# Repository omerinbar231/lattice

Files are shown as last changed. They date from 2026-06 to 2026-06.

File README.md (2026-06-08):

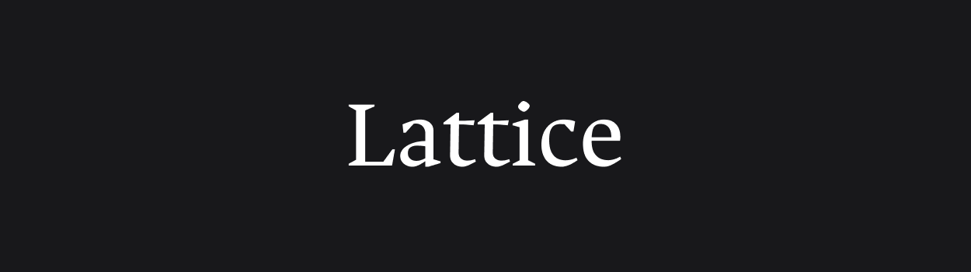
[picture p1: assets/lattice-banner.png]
Lattice


# Lattice Arm: Open Source Modular Detachable Low Cost Robotic Arm for Tool Use





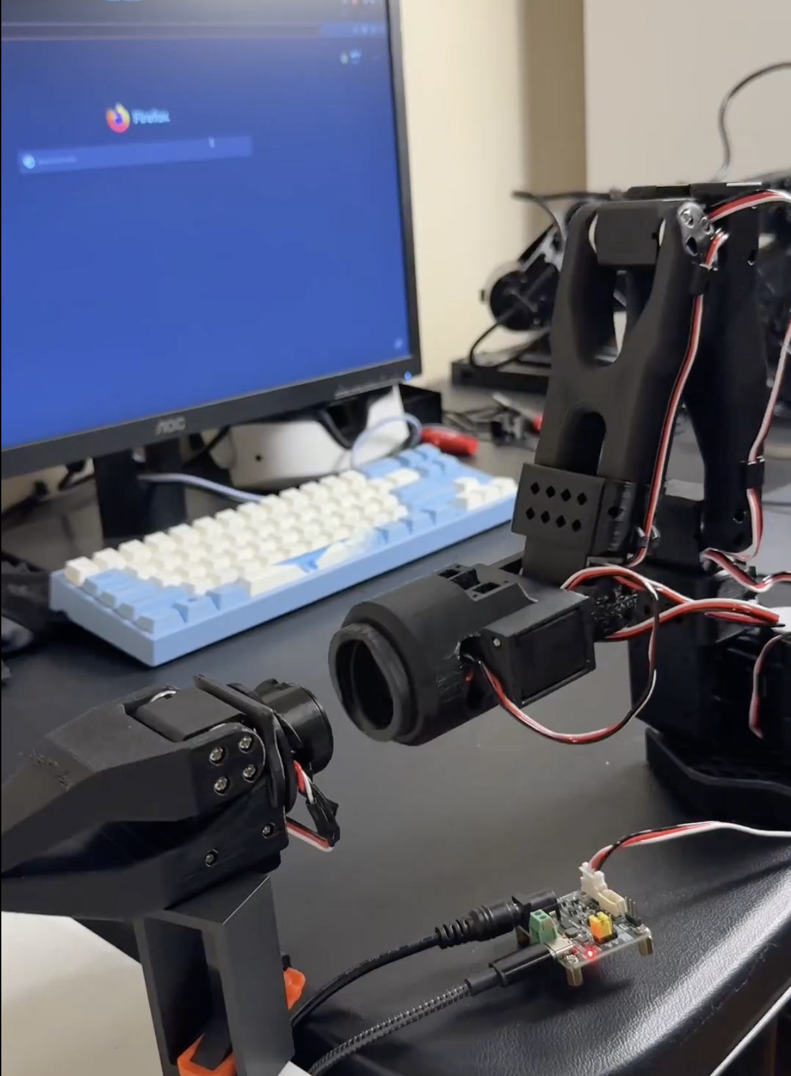
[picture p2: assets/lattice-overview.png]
Lattice overview


Lattice Arm is an open-source, low-cost robotic manipulator designed to be modular and detachable. This repo hosts the hardware design and build resources; pair it with [lerobot](https://github.com/ahadjawaid/lerobot/tree/lattice) on the `lattice` branch to teleoperate on the arm.

## News

- **2026-06-08** — Initial public release.

## BOM

The Lattice Arm reuses the SO-101 follower arm electronics and motors, so the bill of materials is split into the **Lattice** parts (unique to this repo) and the **SO-101 base arm** (the remaining standard parts). One full arm uses **6× Feetech STS 3215 servos** total — 2 in the Lattice upper section and 4 in the SO-101 base. Prices are in USD and referenced from the [SO-101 BOM](https://github.com/TheRobotStudio/SO-ARM100).

### Lattice

| Part | Qty | Unit Cost | Subtotal | Buy |
| --- | --- | --- | --- | --- |
| Feetech STS 3215 Servo 7.4V | 2 | $13.89 | $27.78 | [Seeed](https://www.seeedstudio.com/Feetech-ST-3215-C044-Heavy-Duty-Servo-7-4V-1-191-Gear-Reduction-p-6460.html) |
| 8 Pin Pogo Pin | 1 | $9.99 | $9.99 | [Amazon](https://www.amazon.com/dp/B0DT79W2VD) |
| PLA Filament — `lattice.3mf`, 189.11 g <sup>[1](#filament)</sup> | — | ~$20/kg | ~$3.78 | — |
| Jumper Wires M-M (optional) | 1 | ~$6.99 | — | [Amazon](https://www.amazon.com/dp/B07XJ97KD2) |
| **Total** | | | **~$41.55** | |

> [!NOTE]
> Screws for mounting the motors are included in the Feetech STS 3215 boxes. The optional jumper wires are excluded from the total.

### SO-101 Base Arm

| Part | Qty | Unit Cost | Subtotal | Buy |
| --- | --- | --- | --- | --- |
| Feetech STS 3215 Servo 7.4V | 4 | $13.89 | $55.56 | [Alibaba](https://www.alibaba.com/product-detail/Top-Seller-Low-Cost-Feetech-STS3215_1600999461525.html) |
| Motor Control Board | 1 | $10.60 | $10.60 | [Amazon](https://www.amazon.com/Waveshare-Integrates-Control-Circuit-Supports/dp/B0CTMM4LWK/) |
| USB-C Cable (2 pcs) | 1 | $7.00 | $7.00 | [Amazon](https://www.amazon.com/Charging-etguuds-Charger-Braided-Compatible/dp/B0B8NWLLW2/?th=1) |
| Power Supply | 1 | $10.00 | $10.00 | [Amazon](https://www.amazon.com/Facmogu-Switching-Transformer-Compatible-5-5x2-1mm/dp/B087LY41PV/) |
| Table Clamp (2 pcs) | 1 | $5.00 | $5.00 | [Amazon](https://www.amazon.com/Mr-Pen-Carpenter-Clamp-6inch/dp/B092L925J4/) |
| Screwdriver Set | 1 | $6.00 | $6.00 | [Amazon](https://www.amazon.com/Precision-Phillips-Screwdriver-Electronics-Computer/dp/B0DB227RTH) |
| PLA Filament — SO-101 base parts, 223.91 g <sup>[1](#filament)</sup> | — | ~$20/kg | ~$4.48 | — |
| **Total** | | | **~$98.64** | |

**Full arm total: ~$140.19** (Lattice ~$41.55 + SO-101 base ~$98.64), with **413.02 g** of filament.

<a name="filament">1</a>: Filament cost estimated at ~$20/kg PLA; adjust for your material and supplier.

## Instruction

See [`hardware/README.md`](hardware/README.md) for the print files, part list, and assembly.

## Contribution

Core contributors: **Ahad Jawaid** and **Juan Luna**.

Lattice is an active project and we welcome help. See [CONTRIBUTING.md](CONTRIBUTING.md) for the current roadmap and how to get involved.

## Citation

```bibtex
@misc{jawaid2026lattice,
    author = {Jawaid, Ahad and Luna, Juan},
    title = {Lattice Arm: Open Source Modular Detachable Low Cost Robotic Arm},
    howpublished = "\url{https://github.com/ahadjawaid/lattice}",
    year = {2026}
}
```

## Acknowledgement

Built on top of [SO-ARM100](https://github.com/TheRobotStudio/SO-ARM100) and [LeRobot](https://github.com/huggingface/lerobot). And repo inspired by [XLeRobot](https://github.com/Vector-Wangel/XLeRobot).

## Disclaimer

> [!NOTE]
> If you build, buy, or develop a Lattice Arm based on this repo, you will be fully responsible for all the physical and mental damages it does to you or others. No warranties or guarantees are made regarding safety, performance, or fitness for any particular use.

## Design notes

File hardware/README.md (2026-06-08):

# Lattice Arm Hardware

The Lattice Arm is built on top of the [SO-101](https://github.com/TheRobotStudio/SO-ARM100) arm. This folder contains the 3D-printable parts, CAD source files, and assembly references for the Lattice-specific hardware — everything from the shoulder through the end effector and detachable connectors.

## 3MF Print Files

Two pre-arranged build plates are provided for Bambu Studio (or any slicer that supports `.3mf`).

### Lattice-only parts — `lattice.3mf`

Contains every part unique to the Lattice Arm: shoulder through end effector, including both detachable connectors. Use this if you already have SO-101 base-arm parts and only need to print the Lattice additions.

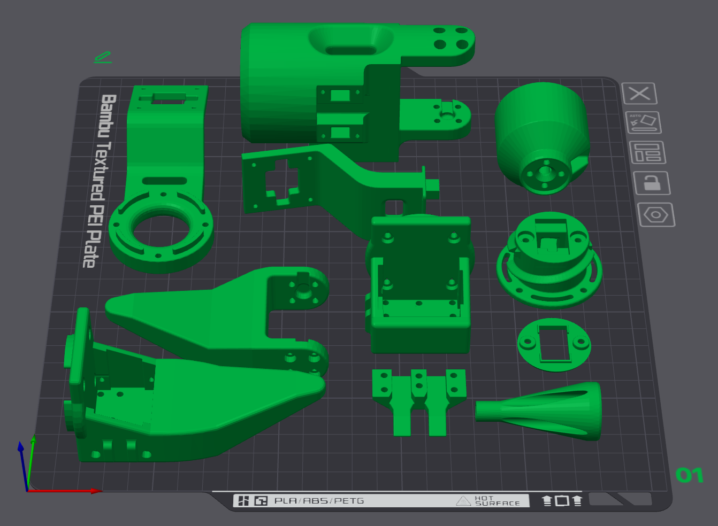
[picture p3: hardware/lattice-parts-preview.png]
Lattice-only print preview


### Full arm — `lattice-full-arm.3mf`

Contains the complete arm on two plates: SO-101 base-arm parts (plate 01) and all Lattice-specific parts (plate 02). Use this for a from-scratch full-arm print.

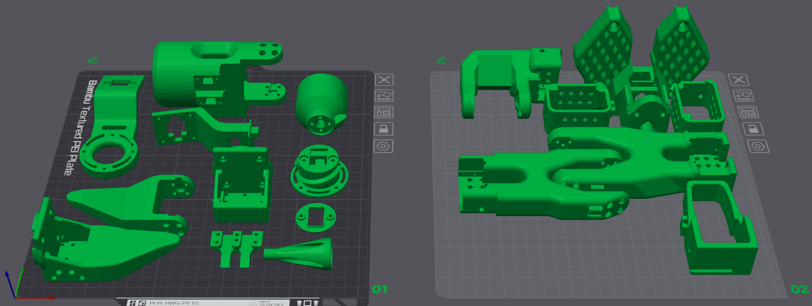
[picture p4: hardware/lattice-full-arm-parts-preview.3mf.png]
Full arm print preview


| File | What it includes |
|---|---|
| [`lattice.3mf`](lattice.3mf) | Lattice-only parts (shoulder → connectors → gripper) |
| [`lattice-full-arm.3mf`](lattice-full-arm.3mf) | SO-101 base parts + all Lattice parts |

## Part Files

Each part folder contains a preview image (`.png`), a mesh for printing (`.stl`), and a CAD source file (`.step`) where available.

| Folder | Parts | Role |
|---|---|---|
| [`Shoulder/`](Shoulder/) | `Shoulder` | Shoulder housing — mounts to the SO-101 base arm |
| [`Shoulder Connector/`](Shoulder%20Connector/) | `ConnectorPartA`, `ConnectorPartAcap` | Detachable shoulder connector |
| [`End Effector Connector/`](End%20Effector%20Connector/) | `ConnectorPartB`, `ConnectorPartBcap` | Detachable wrist / end-effector connector |
| [`End Effectors/Gripper/`](End%20Effectors/Gripper/) | `GripperPartA`, `GripperPartb` | Default parallel-jaw gripper |
| [`End Effectors/Screw Gripper/`](End%20Effectors/Screw%20Gripper/) | `ScrewComponent`, `GeneralMotorCasing` | Alternate screw-driven gripper |
| [`CasingHolder/`](CasingHolder/) | `CasingHolder` | Motor casing mount |
| [`Camera Accessories/`](Camera%20Accessories/) | `CameraAttachment`, `CameraAttachment2` | Optional egocentric camera mounts |

## Assembly

The Lattice upper arm attaches to the SO-101 base and is built in this order, base to tip:

```
SO-101 base arm  →  Shoulder  →  Shoulder Connector  →  End Effector Connector  →  Gripper
```

Each connector pair (`PartA` / `PartAcap`, `PartB` / `PartBcap`) forms a detachable joint so segments can be swapped without disassembling the full arm.

### 1. Shoulder

Mount the shoulder housing onto the SO-101 wrist/base-arm interface. The shoulder is the main structural block with side connector ports and a top cable-routing opening.

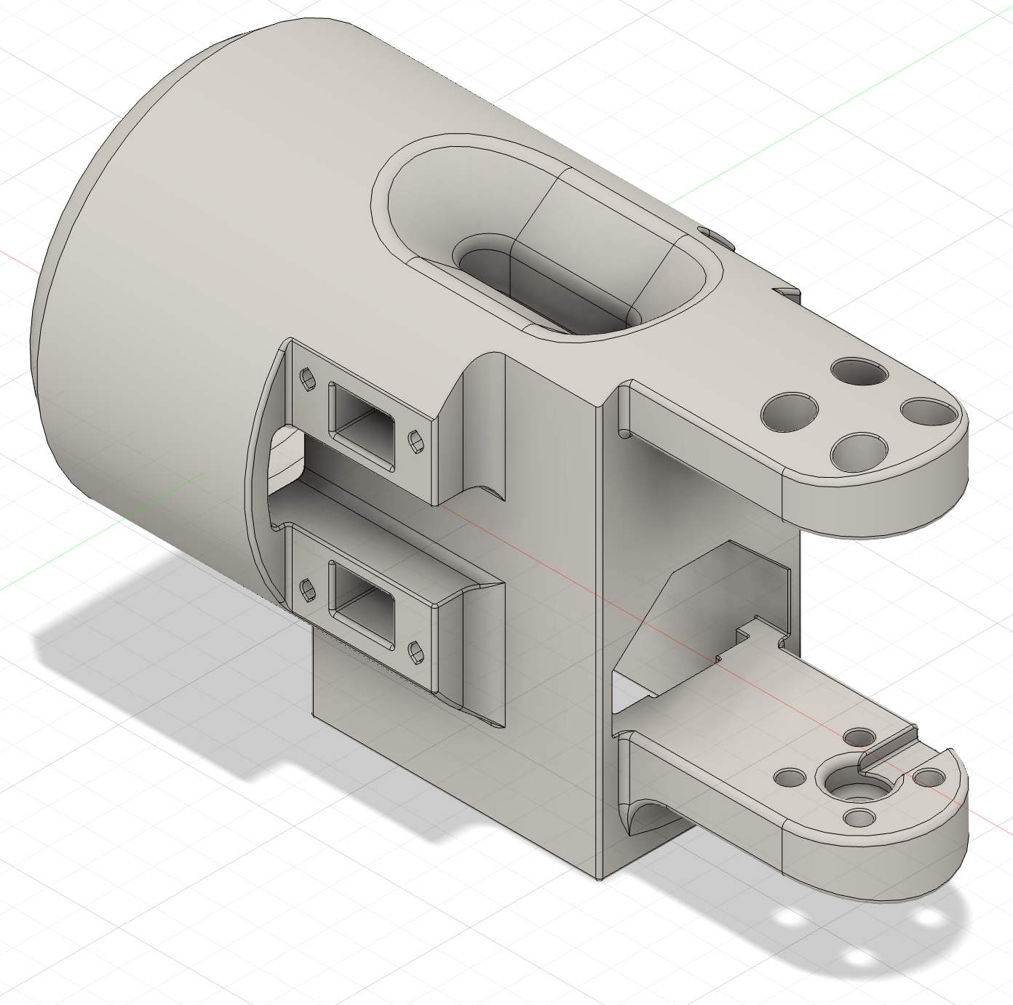
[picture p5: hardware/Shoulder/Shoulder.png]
Shoulder


### 2. Shoulder Connector

Attach `ConnectorPartA` to the shoulder. Seat `ConnectorPartAcap` to complete the detachable shoulder joint. This is the first modular break point — the arm above the shoulder can be removed here.

| Body | Cap |
|---|-----|
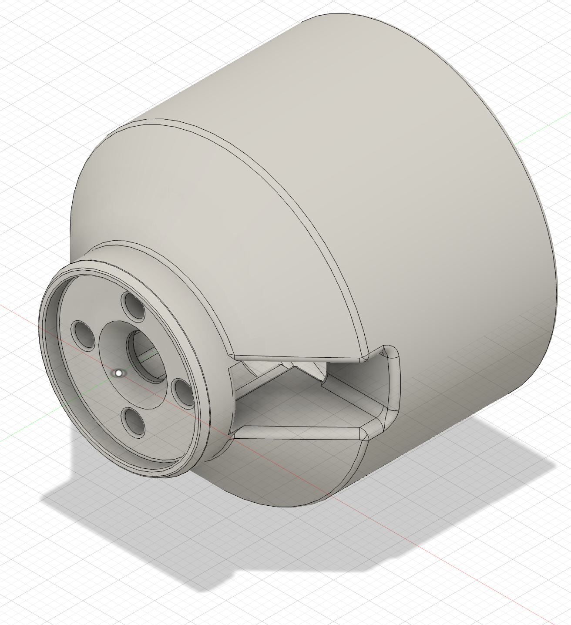
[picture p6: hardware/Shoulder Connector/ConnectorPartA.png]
ConnectorPartA
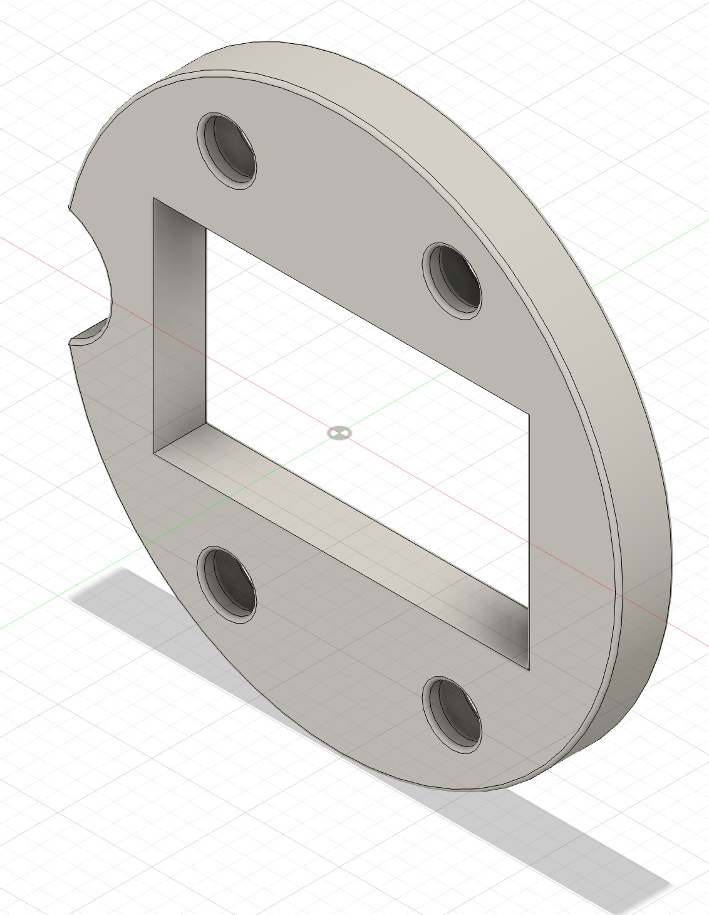
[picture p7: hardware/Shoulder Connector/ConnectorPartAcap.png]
ConnectorPartAcap
|  |  |

### 3. End Effector Connector

Bolt `ConnectorPartB` to the output of the shoulder connector. Attach `ConnectorPartBcap` to form the second detachable joint at the wrist.

| Body | Cap |
|---|-----|
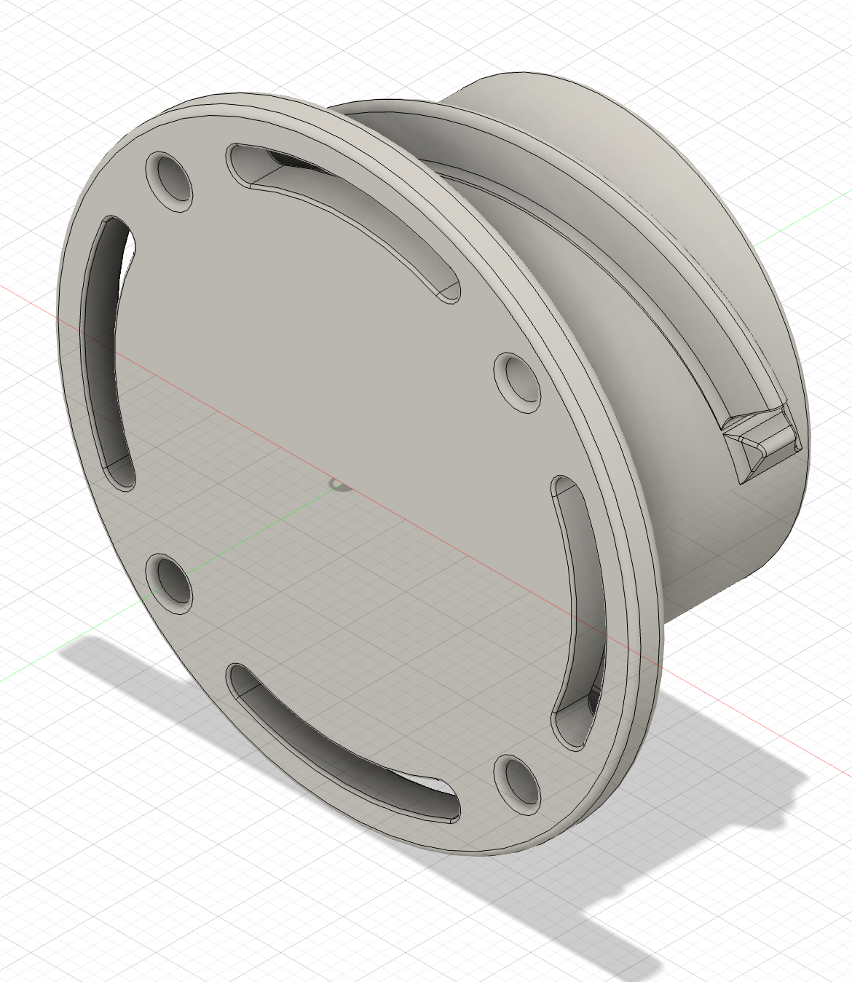
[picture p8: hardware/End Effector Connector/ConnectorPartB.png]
ConnectorPartB
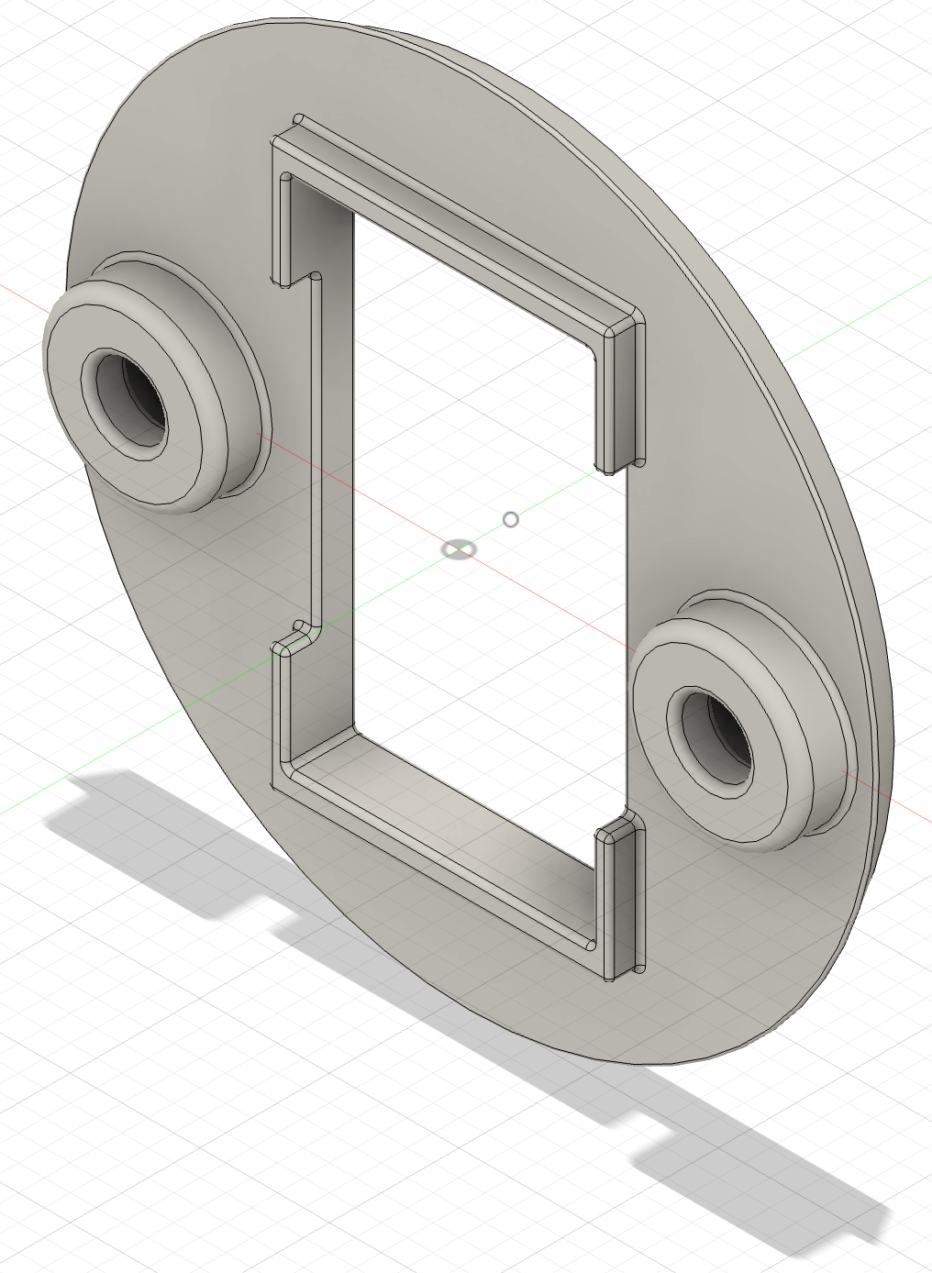
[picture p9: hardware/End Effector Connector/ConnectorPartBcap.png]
ConnectorPartBcap
|  |  |

### 4. Gripper

Mount the gripper onto the end effector connector.

| Finger A | Finger B |
|---|---|
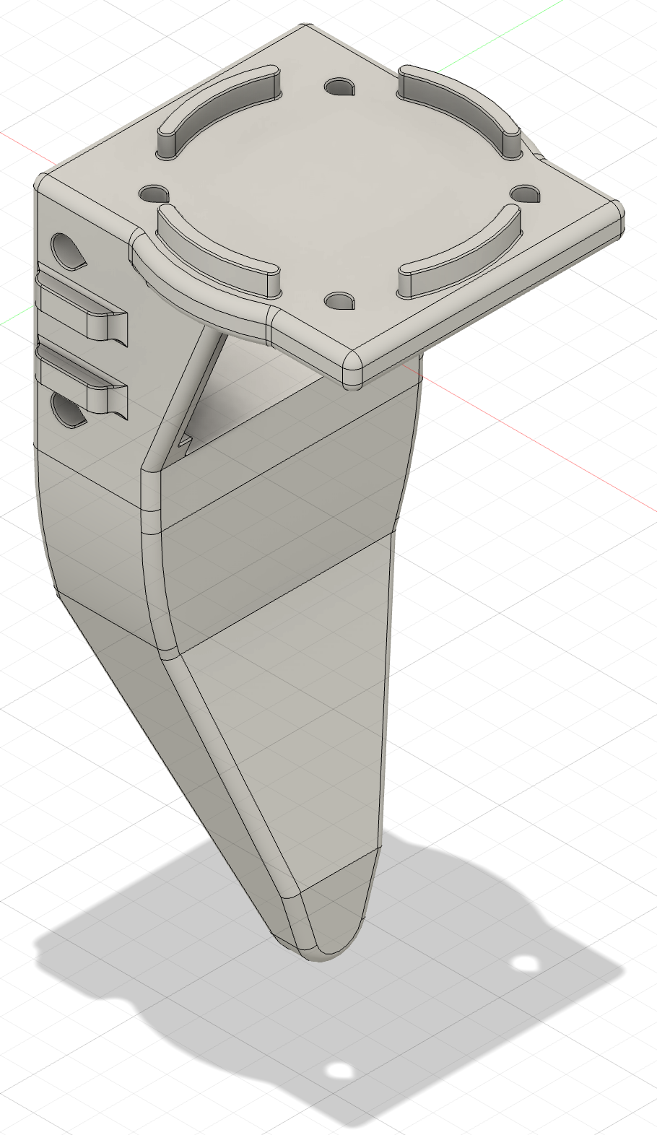
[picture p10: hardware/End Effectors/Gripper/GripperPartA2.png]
GripperPartA
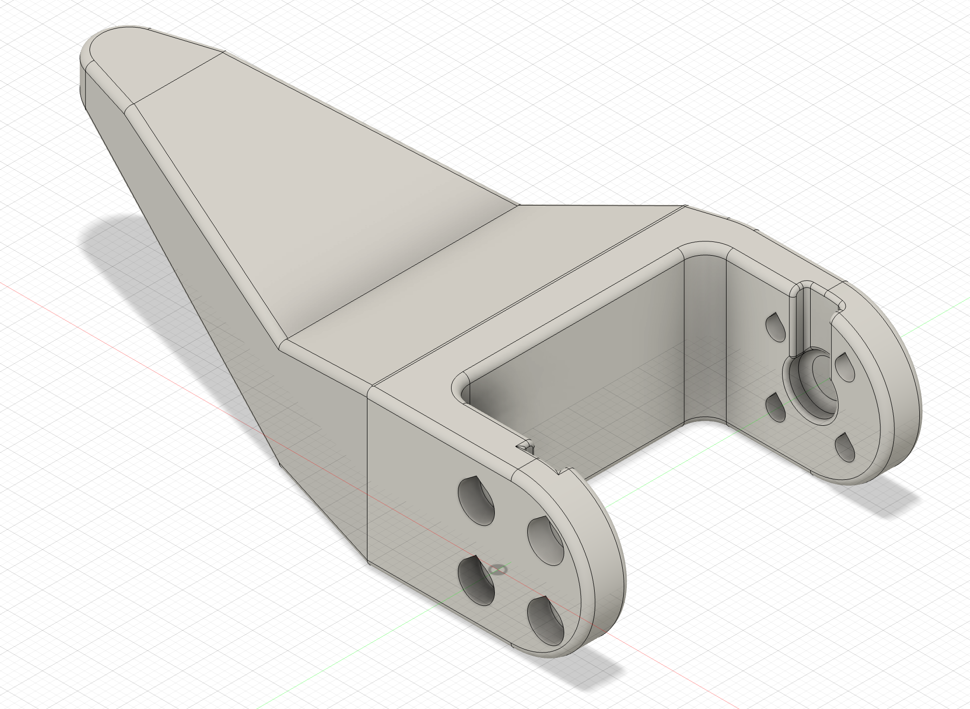
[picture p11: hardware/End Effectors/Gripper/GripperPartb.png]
GripperPartb
|  |  |

Install the gripper servo in [`CasingHolder/CasingHolder`](CasingHolder/CasingHolder.png) if using a dedicated motor housing.

## Optional Accessories

**Screw Gripper** — swap the default gripper for a lead-screw driven variant:

| Screw drive | Motor casing |
|---|---|
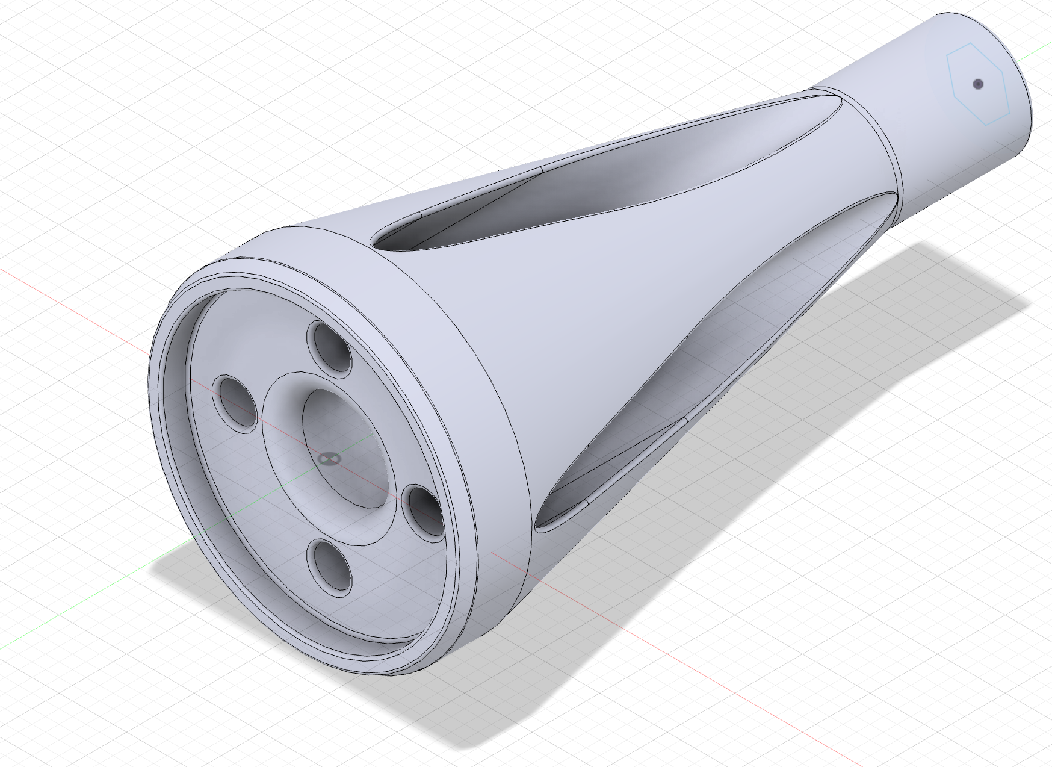
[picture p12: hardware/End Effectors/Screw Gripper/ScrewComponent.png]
ScrewComponent
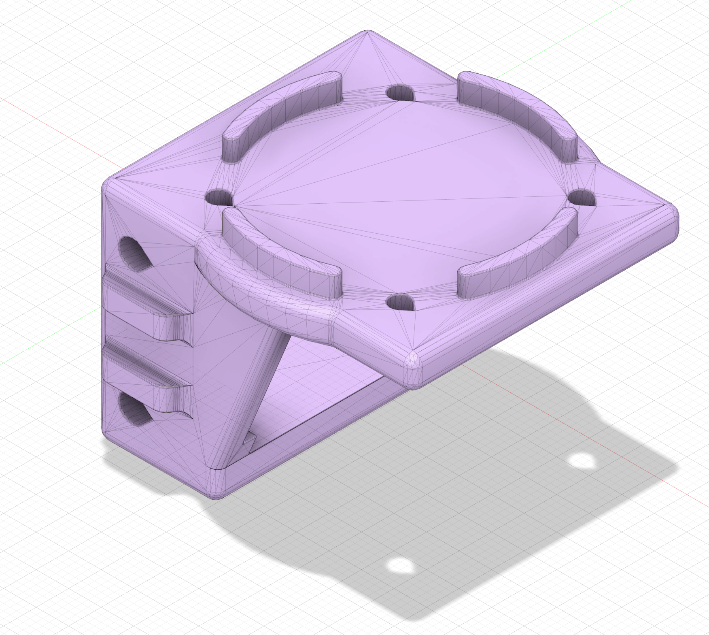
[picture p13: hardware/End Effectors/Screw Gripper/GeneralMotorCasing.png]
GeneralMotorCasing
|  |  |

**Camera mounts** — attach egocentric cameras to the arm:

| Mount A | Mount B |
|---|---|
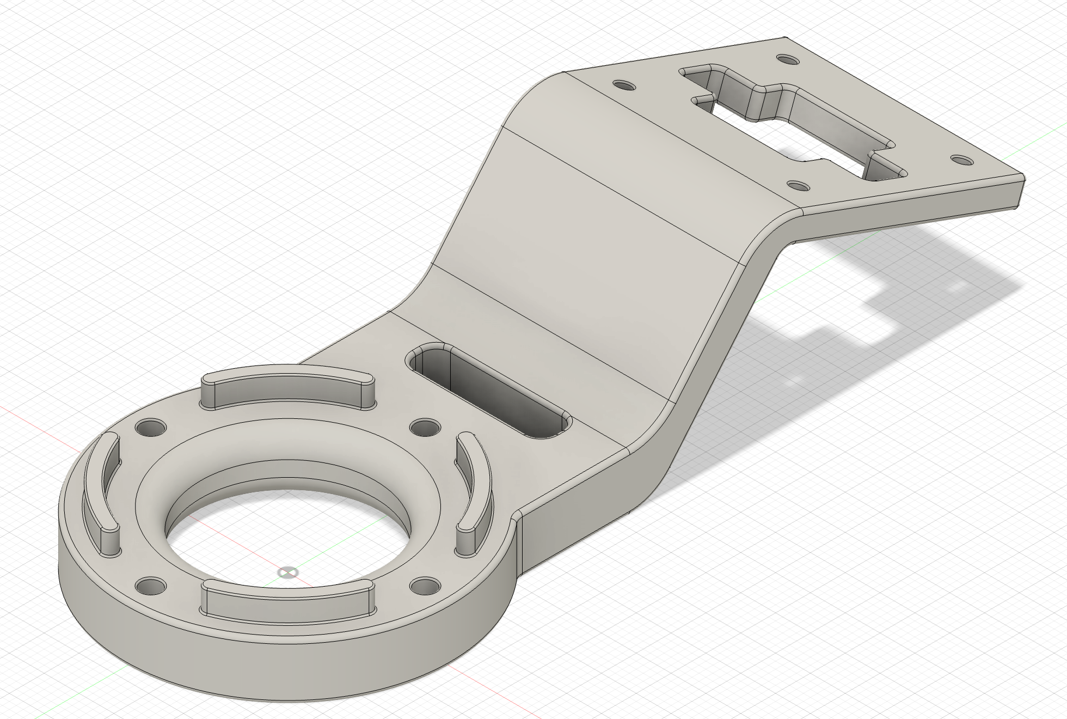
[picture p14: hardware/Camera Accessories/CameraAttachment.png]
CameraAttachment
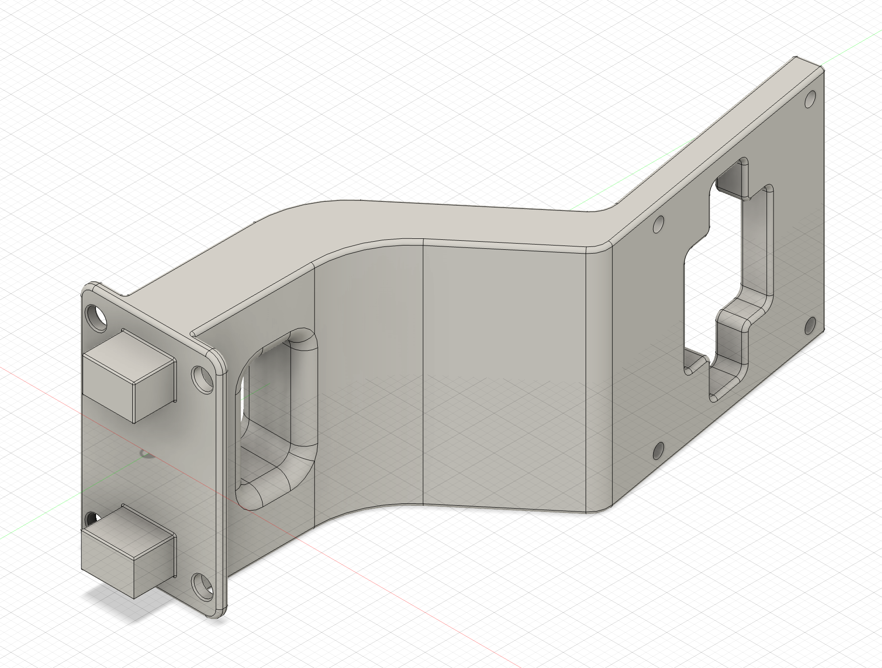
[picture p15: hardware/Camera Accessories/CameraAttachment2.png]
CameraAttachment2
|  |  |

## Software

To teleoperat, use the [lerobot `lattice` branch](https://github.com/ahadjawaid/lerobot/tree/lattice).

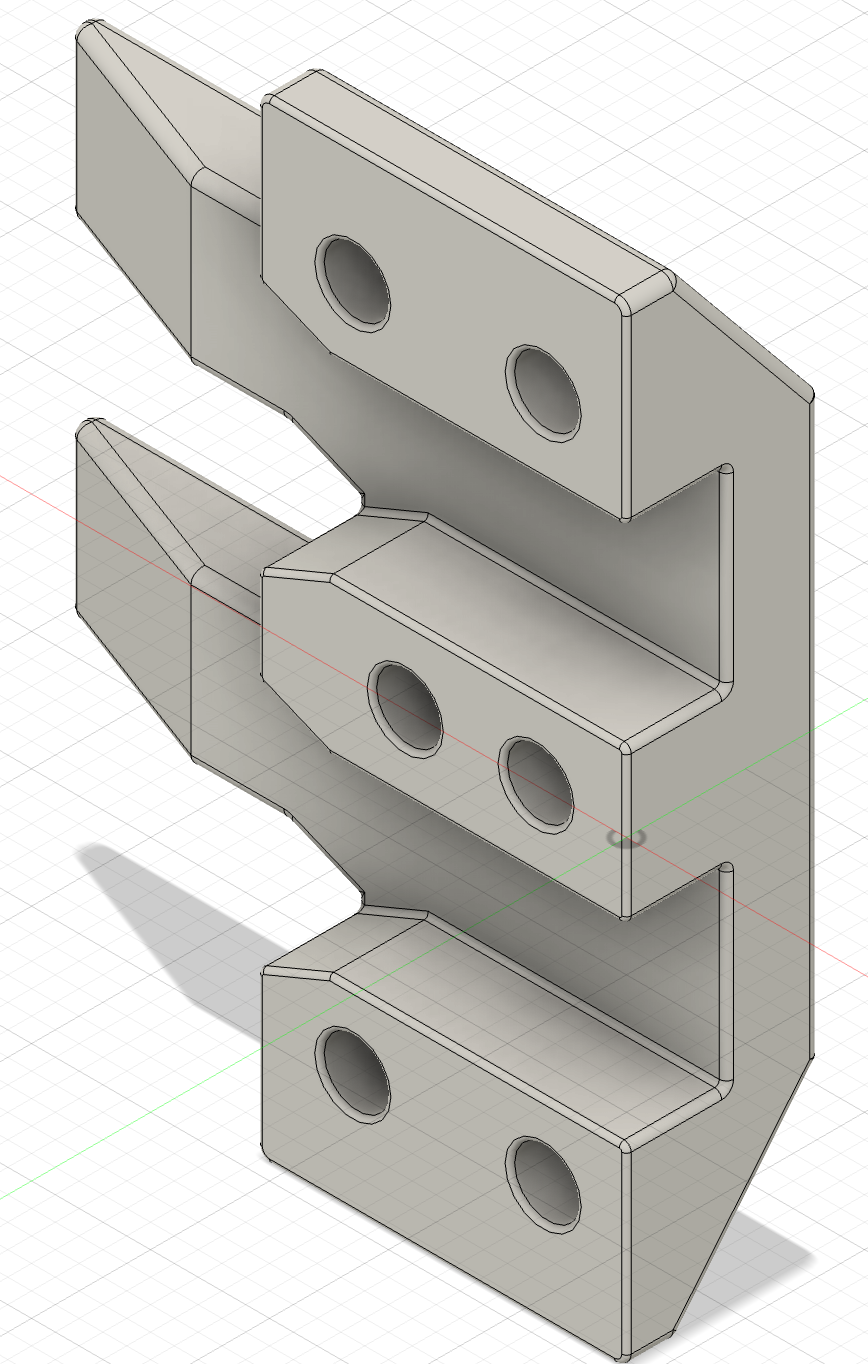
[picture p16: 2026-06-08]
hardware/CasingHolder/CasingHolder.png

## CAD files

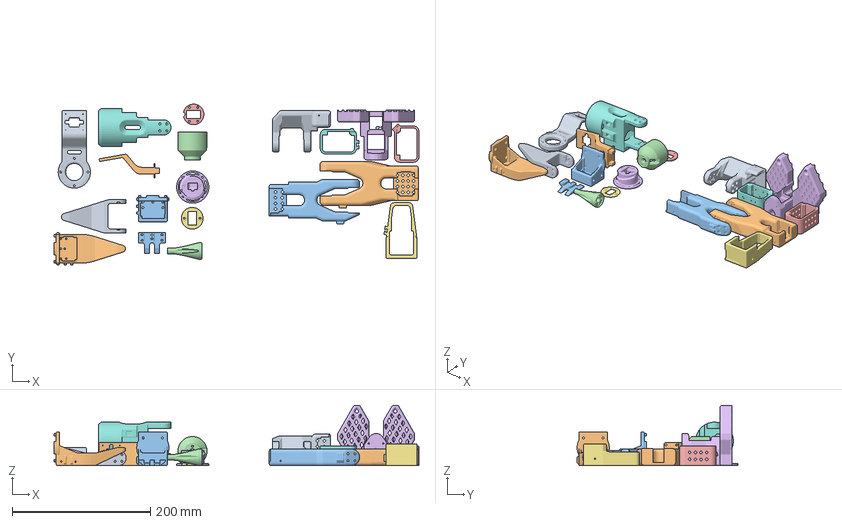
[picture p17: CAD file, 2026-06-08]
hardware/lattice-full-arm.3mf
527.2 x 232.3 x 87.0 mm
CameraAttachment.stl
CameraAttachment2.stl
CasingHolder.stl
ConnectorPartA.stl
ConnectorPartAcap.stl
ConnectorPartB.stl
ConnectorPartBcap.stl
HolderArmPart.stl
GripperPartb.stl
GripperPartA2.stl
GeneralMotorCasing.stl
ScrewComponent.stl
Ender_Follower_SO101.stl_1
Ender_Follower_SO101.stl_2
Ender_Follower_SO101.stl_3
Ender_Follower_SO101.stl_4
Ender_Follower_SO101.stl_5
Ender_Follower_SO101.stl_9
Ender_Follower_SO101.stl_10

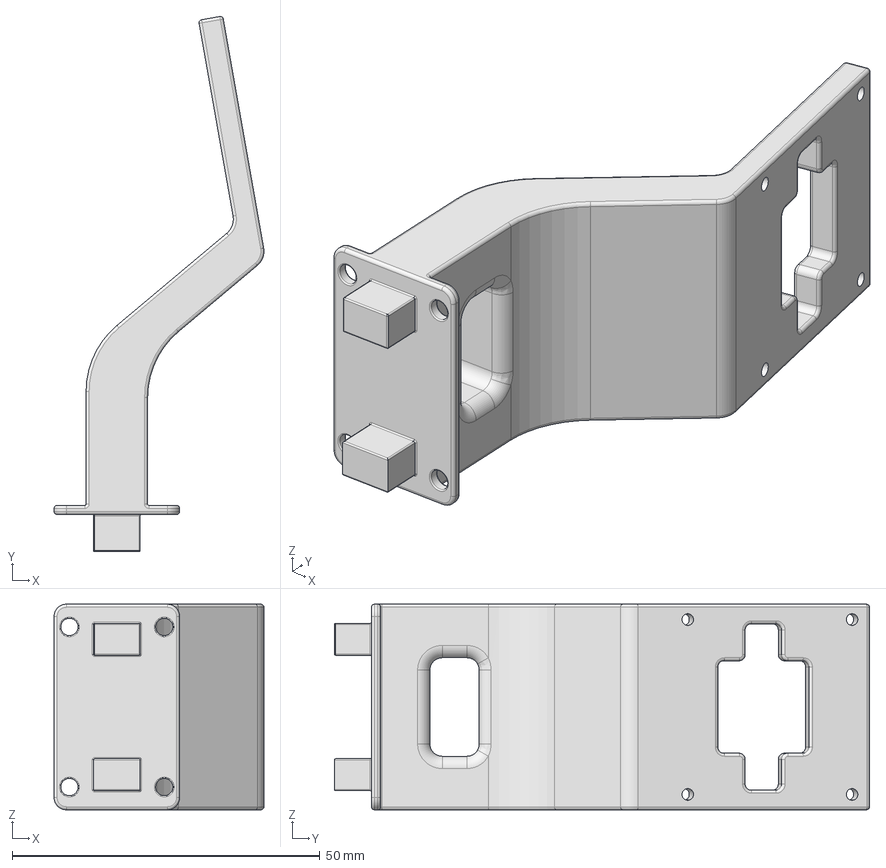
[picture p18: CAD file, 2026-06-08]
hardware/Camera Accessories/CameraAttachment2.step
34.1 x 86.9 x 33.4 mm

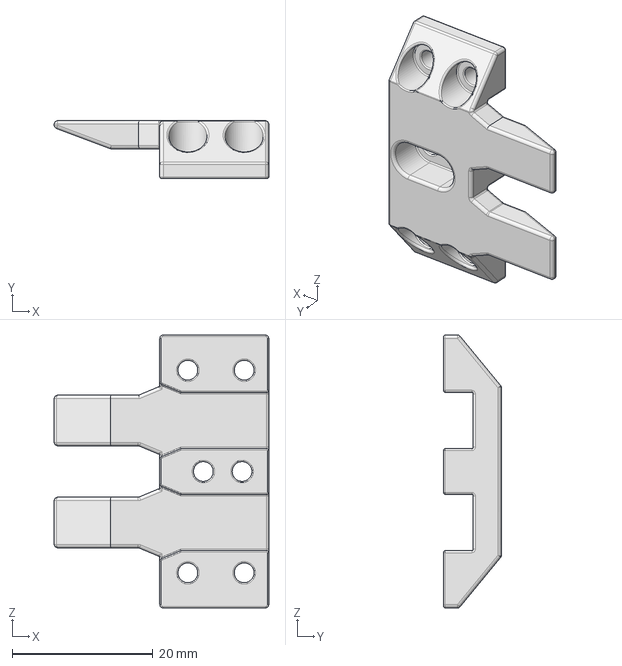
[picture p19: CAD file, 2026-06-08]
hardware/CasingHolder/CasingHolder.step
30.5 x 8.20 x 38.8 mm

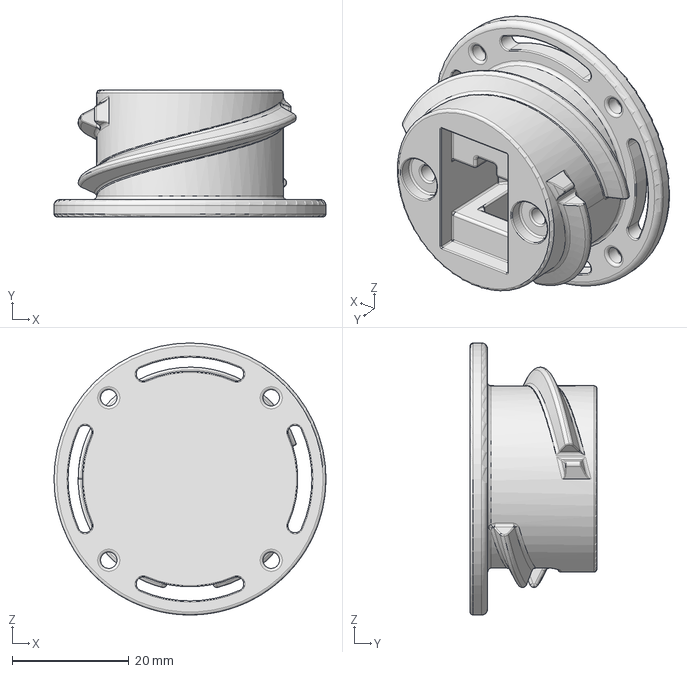
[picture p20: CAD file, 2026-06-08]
hardware/End Effector Connector/ConnectorPartB.step
46.6 x 21.8 x 46.6 mm

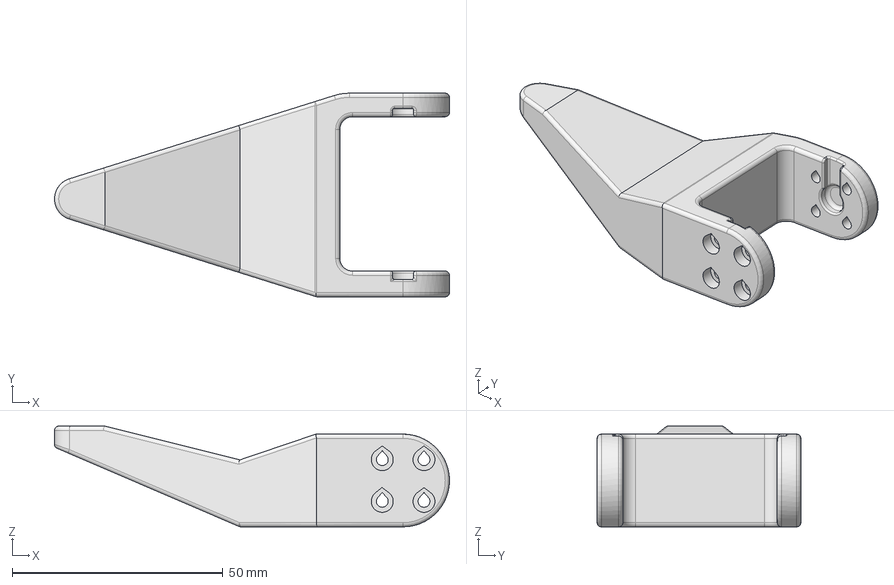
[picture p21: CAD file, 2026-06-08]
hardware/End Effectors/Gripper/GripperPartb.step
93.7 x 48.3 x 23.9 mm

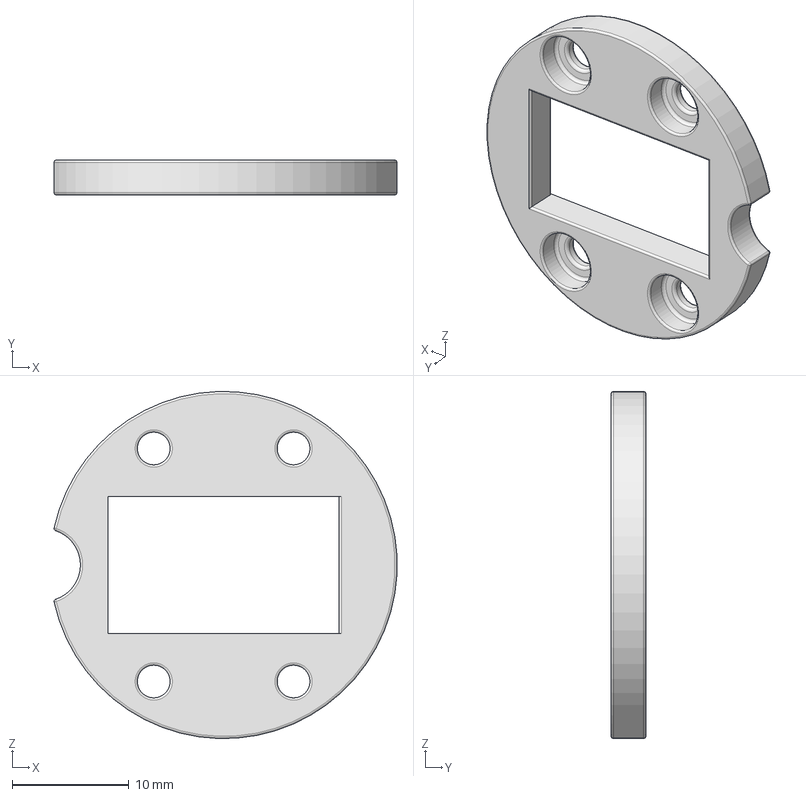
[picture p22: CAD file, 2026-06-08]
hardware/Shoulder Connector/ConnectorPartAcap.step
29.4 x 3.00 x 29.8 mm

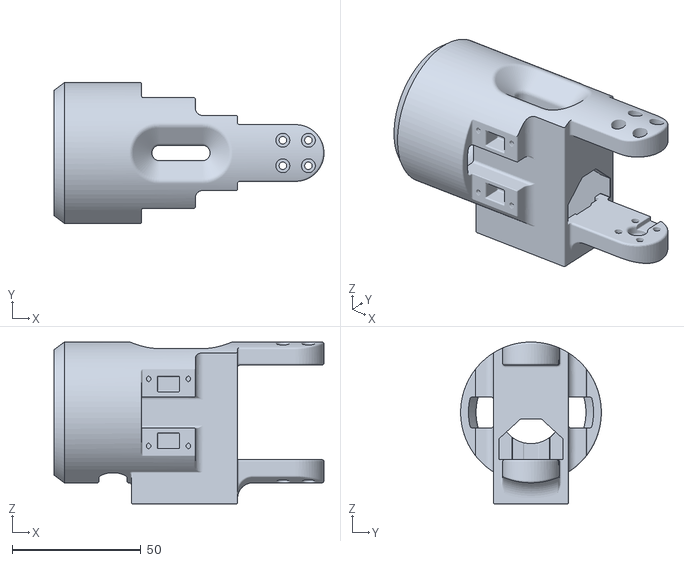
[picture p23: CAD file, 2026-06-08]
hardware/Shoulder/Shoulder.stl
104.7 x 54.6 x 62.8

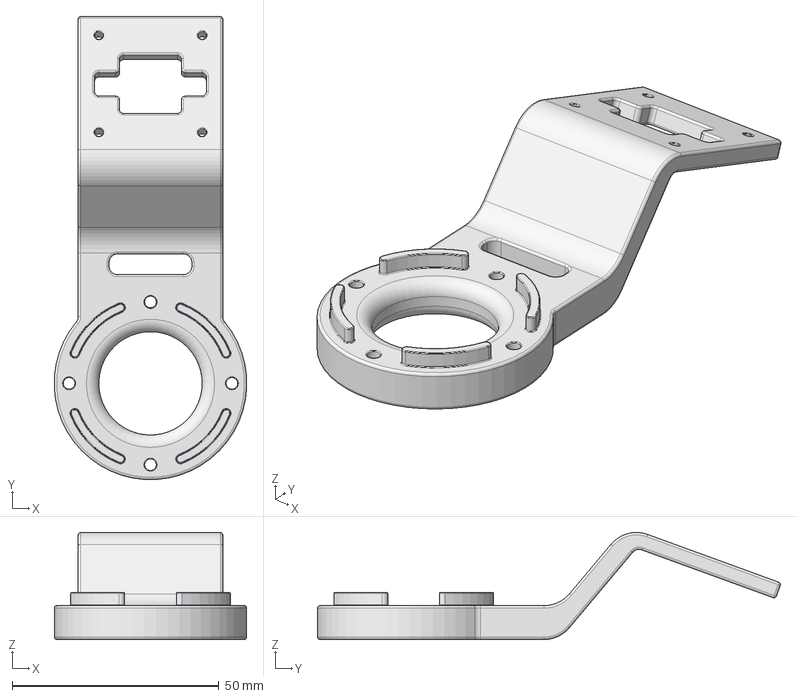
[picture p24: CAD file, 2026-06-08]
hardware/Camera Accessories/CameraAttachment.step
46.6 x 112.1 x 25.9 mm

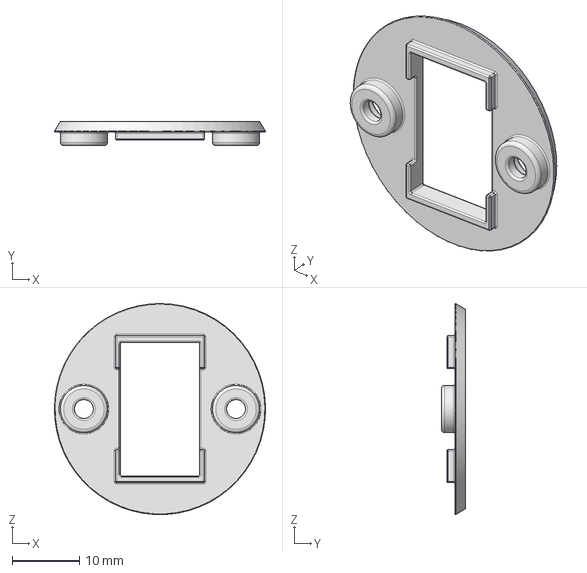
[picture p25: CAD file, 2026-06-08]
hardware/End Effector Connector/ConnectorPartBcap.step
31.3 x 3.60 x 31.3 mm

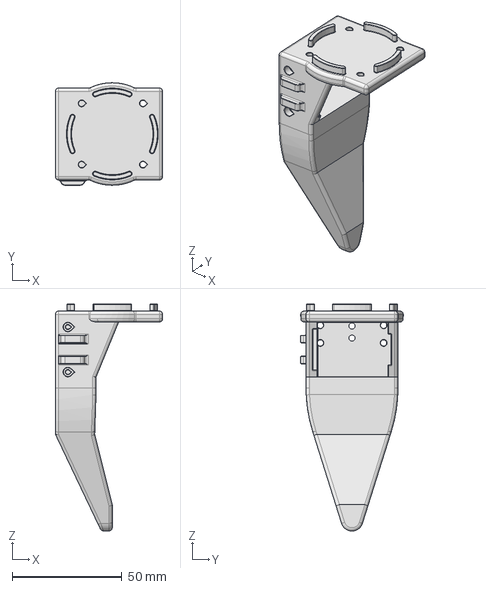
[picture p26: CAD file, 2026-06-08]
hardware/End Effectors/Gripper/GripperPartA2.step
48.8 x 46.6 x 103.2 mm

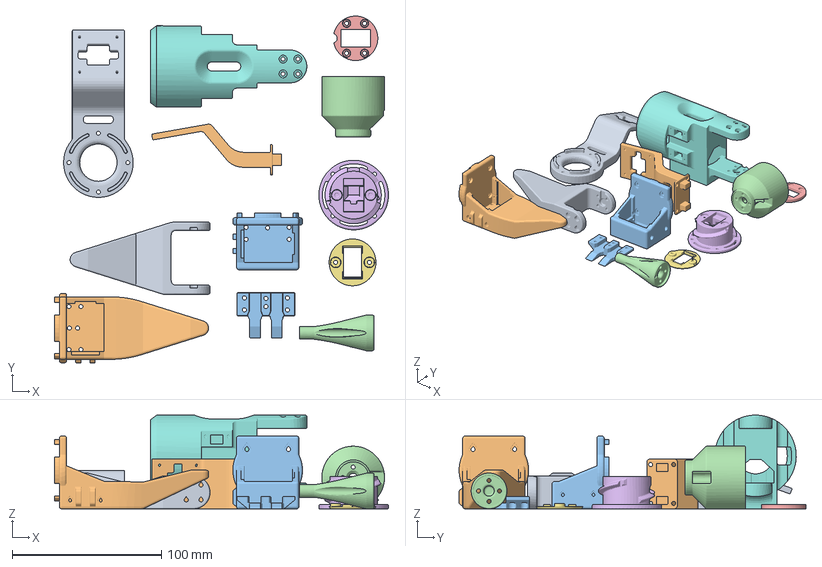
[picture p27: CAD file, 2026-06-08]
hardware/lattice.3mf
223.7 x 232.3 x 62.8 mm
CameraAttachment.stl
CameraAttachment2.stl
CasingHolder.stl
ConnectorPartA.stl
ConnectorPartAcap.stl
ConnectorPartB.stl
ConnectorPartBcap.stl
HolderArmPart.stl
GripperPartb.stl
GripperPartA2.stl
GeneralMotorCasing.stl
ScrewComponent.stl

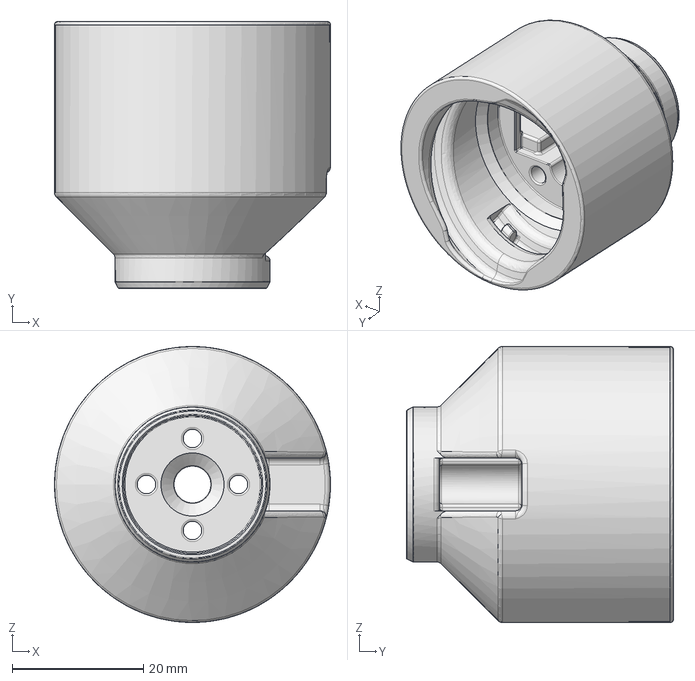
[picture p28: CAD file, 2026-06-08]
hardware/Shoulder Connector/ConnectorPartA.step
42.0 x 40.6 x 42.0 mm

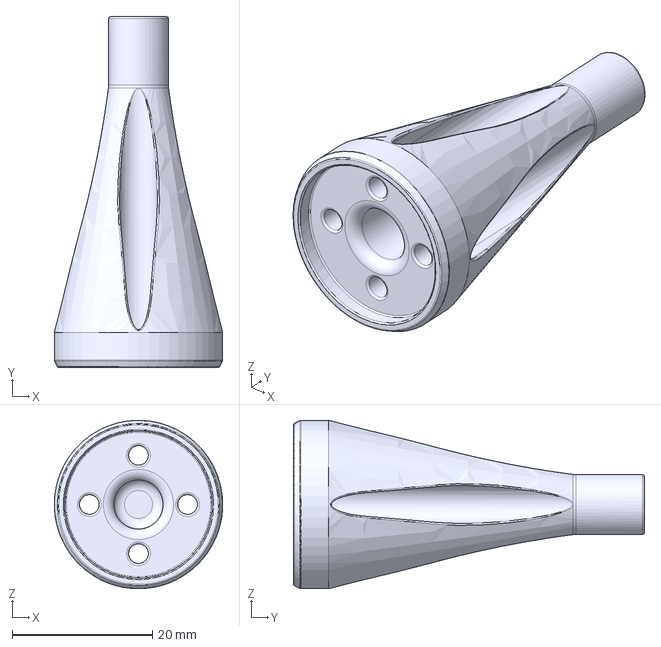
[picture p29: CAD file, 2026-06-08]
hardware/End Effectors/Screw Gripper/ScrewComponent.step
24.0 x 50.0 x 24.0 mm

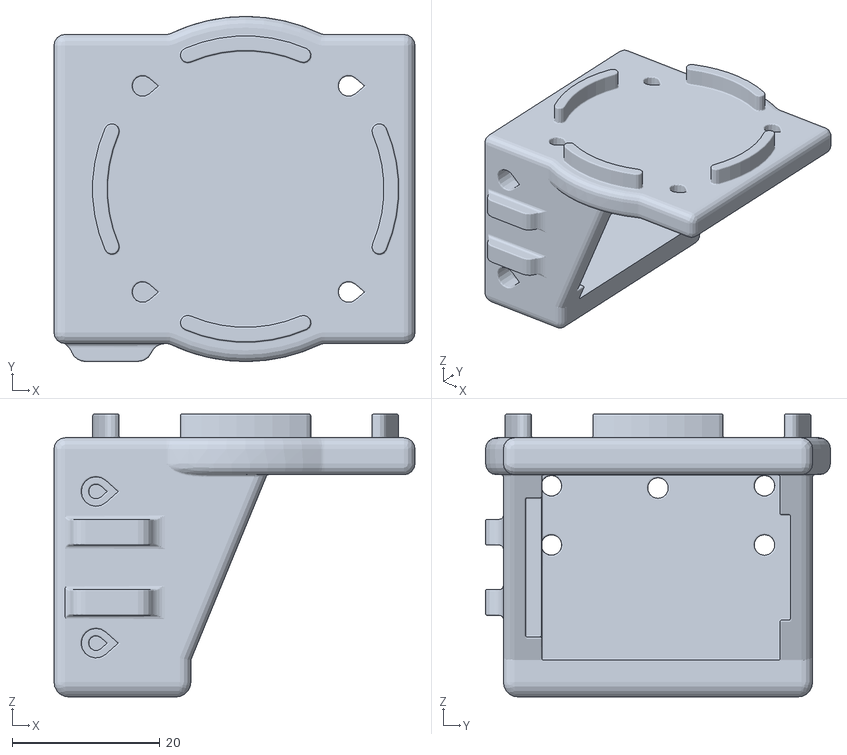
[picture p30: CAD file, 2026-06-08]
hardware/End Effectors/Screw Gripper/GeneralMotorCasing.stl
48.8 x 46.6 x 38.2

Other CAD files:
hardware/Shoulder/HolderArmPart.step
hardware/End Effectors/Gripper/GripperPartA.stl
hardware/Camera Accessories/CameraAttachment.stl
hardware/Camera Accessories/CameraAttachment2.stl
hardware/CasingHolder/CasingHolder.stl
hardware/End Effector Connector/ConnectorPartB.stl
hardware/End Effector Connector/ConnectorPartBcap.stl
hardware/End Effectors/Gripper/GripperPartb.stl
hardware/End Effectors/Screw Gripper/ScrewComponent.stl
hardware/Shoulder Connector/ConnectorPartA.stl
hardware/Shoulder Connector/ConnectorPartAcap.stl

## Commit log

2026-06-08 Add unified hardware assets and badge-style README links.
    Group STL, STEP, and preview images by component and replace plain nav links with shields.io badges including Twitter follow.
    [CameraAttachment.step, CameraAttachment.stl, CameraAttachment2.step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]
2026-06-08 Link lerobot lattice branch for arm control software.
    Add a README badge and intro pointer to the ahadjawaid/lerobot fork on the lattice branch.
2026-06-08 Expand docs, BOM, and hardware layout for Lattice Arm.
    Add itemized BOM tables, hardware assembly guide, contribution roadmap, full-arm 3MF assets, and reorganize end effectors under hardware/End Effectors while fixing shoulder naming.
    [ConnectorPartA.step, ConnectorPartA.stl, ConnectorPartAcap.step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]

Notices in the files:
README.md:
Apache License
